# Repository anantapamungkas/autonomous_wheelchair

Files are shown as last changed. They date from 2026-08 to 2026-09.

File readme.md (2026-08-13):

## 📁 Struktur Repositori

Rrepositori terdiri dari beberapa komponen utama:
*   **`assets/`**: 
*   **`firmware/`**: 
*   **`hardware/`**: 
*   **`ros_ws/`**: 
*   **`scripts/`**: 

## Spesifikasi Perangkat Keras (Hardware)

<p align="center">
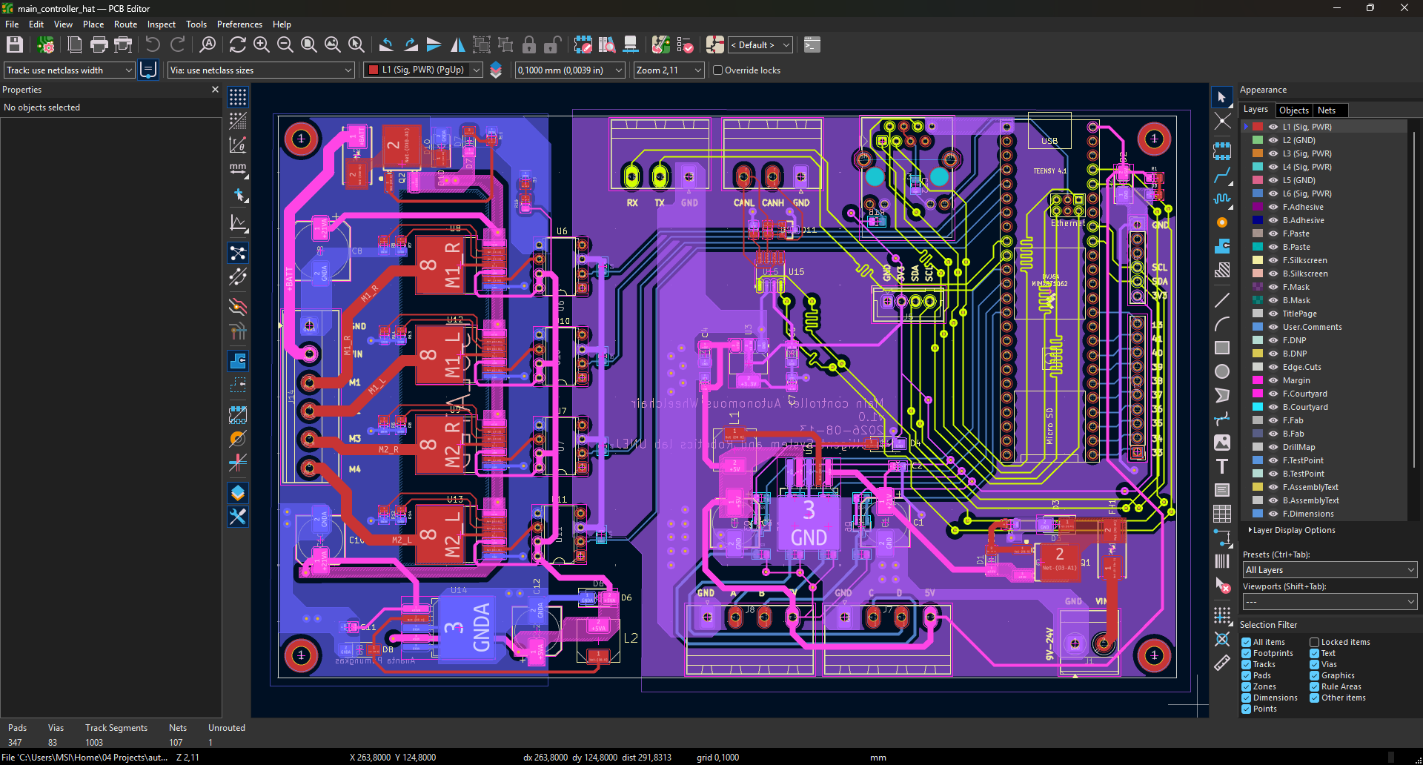
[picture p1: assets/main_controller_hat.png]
Sistem Arsitektur Kursi Roda Otonom
  
</p>

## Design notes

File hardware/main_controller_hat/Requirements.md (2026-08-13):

# Hardware Requirements & System Architecture Document

**Project Name:** Autonomous Wheelchair Main Controller
**Document Owner:** Ananta Pamungkas  
**Date:** 13-08-2026  
**Version:** 1.0

---

## 1. Executive Summary

## 2. System Objectives

## 3. Functional Requirements
### 3.1 Core Processing & Firmware

### 3.2 Power Management & Distribution

### 3.3 Sensing & Inputs (Peripherals)

### 3.4 Actuation & Outputs

## 4. Non-Functional Requirements

## 5. System Architecture
### 5.1 High-Level Block Diagram

### 5.2 Communication Buses & Bandwidth

## 6. Subsystem Validation & Prototyping Plan

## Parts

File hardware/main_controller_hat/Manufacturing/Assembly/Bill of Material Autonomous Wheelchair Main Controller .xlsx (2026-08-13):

Total
Rp 355483
Barang | Jenis | Jumlah | Satuan | Harga Satuan | Total Harga | Ongkir | Link Pembelian
cap elco(polar)_8x10_220uF | Capacitor | 4 | pcs | Rp 1000 | Rp 4000 |  | https://tk.tokopedia.com/ZS4wJxB6g/
cap tantalum_0805_1uF | Capacitor | 1 | strip | Rp 5000 | Rp 5000 |  | https://tk.tokopedia.com/ZS4wSyJWV/
cap tantalum_0805_4.7uF | Capacitor | 2 | pcs | Rp 1000 | Rp 2000 |  | https://tk.tokopedia.com/ZS4wRrhET/
cap elco(polar)_10x10_470uF | Capacitor | 1 | pcs | Rp 4000 | Rp 4000 |  | https://tk.tokopedia.com/ZS4wLvY1n/
cap tantalum_0805_100nF | Capacitor | 1 | strip | Rp 2500 | Rp 2500 |  | https://tk.tokopedia.com/ZS4wAxYDJ/
res smd_0805_2.2K | Resistor | 1 | strip | Rp 1500 | Rp 1500 |  | https://tk.tokopedia.com/ZS4wMq25k/
res smd_0805_100K | Resistor | 1 | strip | Rp 1000 | Rp 1000 |  | https://tk.tokopedia.com/ZS4oMhxKQ/
res smd_0805_10K | Resistor | 2 | strip | Rp 1000 | Rp 2000 |  | https://tk.tokopedia.com/ZS4wMEAE6/
res smd_0805_120 | Resistor | 1 | strip | Rp 1500 | Rp 1500 |  | https://tk.tokopedia.com/ZS4wpNDbM/
res smd_0805_1K | Resistor | 1 | strip | Rp 1000 | Rp 1000 |  | https://tk.tokopedia.com/ZS4wpRMPs/
diode_tvs(esd)_5V (LESD5Z5.0T1G) | Diode | 2 | pcs | Rp 899 | Rp 1798 |  | https://tk.tokopedia.com/ZS4wBeh6h/
diode_tvs(esd)_3V (LESD5Z3.3T1G) | Diode | 2 | pcs | Rp 899 | Rp 1798 |  | https://tk.tokopedia.com/ZS4wBrvKN/
diode_zener_10V (LL34) | Diode | 2 | pcs | Rp 845 | Rp 1690 |  | https://tk.tokopedia.com/ZS4wfYXWT/
diode_zener_11V (LL34) | Diode | 2 | pcs | Rp 845 | Rp 1690 |  | https://tk.tokopedia.com/ZS4wfS8Bo/
diode_schotty (SS34) | Diode | 2 | pcs | Rp 635 | Rp 1270 |  | https://tk.tokopedia.com/ZS4wUPosg/
diode_esd (PESD1CAN) | Diode | 1 | pcs | Rp 2546 | Rp 2546 |  | https://tk.tokopedia.com/ZS4wyAvPt/
diode_led_blue (LED 0805 SMD Biru ) | Diode | 2 | pcs | Rp 2000 | Rp 4000 |  | https://tk.tokopedia.com/ZS4wP6N2M/
fuse_holder | Fuse | 2 | pcs | Rp 3163 | Rp 6326 |  | https://tk.tokopedia.com/ZS4w59JFq/
fuse 3A | Fuse | 2 | pcs | Rp 2530 | Rp 5060 |  | https://tk.tokopedia.com/ZS4oMvqqV/
fuse 4A | Fuse | 2 | pcs | Rp 2530 | Rp 5060 |  | https://tk.tokopedia.com/ZS4orx7j3/
fuse 5A | Fuse | 2 | pcs | Rp 2530 | Rp 5060 |  | https://tk.tokopedia.com/ZS4wmRkgq/
LM2596S-5 | ICs | 2 | pcs | Rp 25000 | Rp 50000 |  | https://tk.tokopedia.com/ZS4waEnr3/
AMS1117-3.3 | ICs | 1 | pcs | Rp 2500 | Rp 2500 |  | https://tk.tokopedia.com/ZS4wa7tE5/
6N137 (optocoupler) | ICs | 4 | pcs | Rp 9000 | Rp 36000 |  | https://tk.tokopedia.com/ZS4wmX5g8/
SN65HVD230 | ICs | 1 | pcs | Rp 22828 | Rp 22828 |  | https://tk.tokopedia.com/ZS4wue4fP/
BTS7960 (Driver Motor) | ICs | 4 | pcs | Rp 21000 | Rp 84000 |  | https://tk.tokopedia.com/ZS4wuGqSw/
Inductor_33uH | Inductor | 2 | pcs | Rp 4000 | Rp 8000 |  | https://tk.tokopedia.com/ZS4wHDvvq/
IRFR5305 | Transistor | 2 | pcs | Rp 24900 | Rp 49800 |  | https://tk.tokopedia.com/ZS4w91Kqe/
BSS138 | Transistor | 4 | pcs | Rp 1000 | Rp 4000 |  | https://tk.tokopedia.com/ZS4w9BYNe/
KF2EDG-3p | Terminal / Connector | 2 | buah | Rp 4500 | Rp 9000 |  | https://tk.tokopedia.com/ZS4wCQL4b/
KF2EDG-4p | Terminal / Connector | 2 | buah | Rp 6000 | Rp 12000 |  | https://tk.tokopedia.com/ZS4wC4dEW/
RJ45 | Terminal / Connector | 1 | buah | Rp 5500 | Rp 5500 |  | https://tk.tokopedia.com/ZS4w4qQNN/
KF128-2p | Terminal / Connector | 1 | buah | Rp 1800 | Rp 1800 |  | https://tk.tokopedia.com/ZS4wgyw8m/
KF128-6p | Terminal / Connector | 1 | buah | Rp 2600 | Rp 2600 |  | https://tk.tokopedia.com/ZS4wgAeRV/
pin header | Terminal / Connector | 4 | buah | Rp 1000 | Rp 4000 |  | https://tk.tokopedia.com/ZS4wgnHRS/
JST XH 2.54 | Terminal / Connector | 1 | buah | Rp 2657 | Rp 2657 |  | https://tk.tokopedia.com/ZS4wp5hqA/

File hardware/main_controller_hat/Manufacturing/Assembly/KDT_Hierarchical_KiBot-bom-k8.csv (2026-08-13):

# | Qty | Reference | Value | Datasheet | Footprint | Description | Manufacturer | Manufacturer Part Number
1 | 83 | C1,C2,C3,C4,C5,C6,C7,C8,C10,C11,C12,C13,D1,D2,D3,D4,D5,D6,D7,D8,D9,D10,D11,FH1,FH2,J1,J2,J3,J4,J5,J6,J7,J8,J9,J14,L1,L2,Q1,Q2,Q3,Q4,Q5,Q6,R1,R2,R3,R4,R5,R6,R7,R8,R9,R10,R11,R12,R13,R14,R15,R16,R17,R18,R19,R20,R21,R22,R23,R24,R25,R26,R27,U1,U3,U5,U6,U7,U8,U9,U10,U11,U12,U13,U14,U15 | 01550900M,100K,100nF,10K,120,1K,1uF,2.2K,21V Li ion,220uF,33uH,4.7uF,470uF,6N137,AMS1117-3.3,BSS138,BTS7960B,BZV55B12,Blue,CAN 1,CMPS14,Conn_01x04_Pin,Conn_01x10_Pin,D_TVS,ENC A,ENC B,IRFR5305,LM2596S-5,PESD1CAN,215,RJ45_Hanrun_HR911105A_Horizontal,SMAJ24A,SN65HVD230,SS34,Screw_Terminal_01x06,Teensy4.1,UART | http://www.advanced-monolithic.com/pdf/ds1117.pdf,http://www.ti.com/lit/ds/symlink/lm2596.pdf,http://www.ti.com/lit/ds/symlink/sn65hvd230.pdf,https://assets.n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 | BTS7960B:DPAK127P1490X440-8N,Capacitor_SMD:CP_Elec_10x10,Capacitor_SMD:CP_Elec_8x10.5,Capacitor_SMD:C_0603_1608Metric,Capacitor_SMD:C_0603_1608Metric_Pad1.08x0.95mm_HandSolder,Capacitor_SMD:C_1206_3216Metric_Pad1.33x1.80mm_HandSolder,Connector_JST:JST_XH_B4B-XH-A_1x04_P2.50mm_Vertical,Connector_Phoenix_MSTB:PhoenixContact_MSTBA_2,5_3-G-5,08_1x03_P5.08mm_Horizontal,Connector_Phoenix_MSTB:PhoenixContact_MSTBA_2,5_4-G-5,08_1x04_P5.08mm_Horizontal,Connector_PinHeader_2.54mm:PinHeader_1x06_P2.54mm_Vertical,Connector_PinHeader_2.54mm:PinHeader_1x10_P2.54mm_Vertical,Connector_RJ:RJ45_Hanrun_HR911105A_Horizontal,DR74-330-R:INDM7676X435N,Diode_SMD:D_MiniMELF,Diode_SMD:D_SMA,PCM_SparkFun-LED:LED_0805_2012Metric,PCM_SparkFun-Resistor:R_0805_2012Metric,Package_DIP:DIP-8_W7.62mm,Package_SO:SOIC-8_3.9x4.9mm_P1.27mm,Package_TO_SOT_SMD:SOT-223-3_TabPin2,Package_TO_SOT_SMD:SOT-23,Package_TO_SOT_SMD:TO-263-5_TabPin3,Resistor_SMD:R_0603_1608Metric_Pad0.98x0.95mm_HandSolder,TerminalBlock_Phoenix:TerminalBlock_Phoenix_MKDS-1,5-6-5.08_1x06_P5.08mm_Horizontal,TerminalBlock_Phoenix:TerminalBlock_Phoenix_MKDS-3-2-5.08_1x02_P5.08mm_Horizontal,easyeda2kicad:FUSE-SMD_L9.8-W5.0_01550900M,easyeda2kicad:SMA_L4.4-W2.8-LS5.4-R-RD,easyeda2kicad:SOT-23_L2.9-W1.3-P1.90-LS2.4-BR,easyeda2kicad:TO-252-3_L6.6-W6.1-P4.58-LS10.1-BR-1,teensy:Teensy41 | 1 Port RJ45 Magjack Connector Through Hole 10/100 Base-T, AutoMDIX,12V, 500mW, 2%, Zener diode, MiniMELF,1A Low Dropout regulator, positive, 3.3V fixed output, SOT-223,400W unidirectional Transient Voltage Suppressor, 24.0Vr, SMA(DO-214AC),50V Vds, 0.22A Id, N-Channel MOSFET, SOT-23,5V 3A Step-Down Voltage Regulator, TO-263,Bidirectional transient-voltage-suppression diode,CAN Bus Transceivers, 3.3V, 1Mbps, Low-Power capabilities, SOIC-8,Generic connector, single row, 01x02, script generated,Generic connector, single row, 01x04, script generated,Generic connector, single row, 01x06, script generated,Generic connector, single row, 01x10, script generated,Generic screw terminal, single row, 01x03, script generated (kicad-library-utils/schlib/autogen/connector/),Generic screw terminal, single row, 01x04, script generated (kicad-library-utils/schlib/autogen/connector/),Generic screw terminal, single row, 01x06, script generated (kicad-library-utils/schlib/autogen/connector/),Inductor,Light emitting diode,PESD1CAN,Polarized capacitor,Polarized capacitor, US symbol,Resistor,Schottky diode,Single High Speed LSTTL/TTL Compatible Optocoupler with enable, dV/dt 1000/us, VCM 10, max 7V VCC, DIP-8,Unpolarized capacitor | Littelfuse(美国力特),Nexperia(安世),Slkor(萨科微)

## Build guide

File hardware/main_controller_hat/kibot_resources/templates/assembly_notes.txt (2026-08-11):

ASSEMBLY NOTES (UNLESS OTHERWISE SPECIFIED)

1)	DO NOT POPULATE PARTS ARE MARKED WITH A RED CROSS.

2)	DO NOT POPULATE PARTS ARE NOT PRESENT IN THE BOM.

3)	IF CONFLICTING INFORMATION IS FOUND BETWEEN THE ASSEMBLY
	FILE AND BOM, BOM SHOULD BE USED AS THE MAIN SOURCE.

4)	CONFORMAL COATING IS NOT REQUIRED.

5)	DOT IDENTIFIES PIN #1 LOCATION AND DEVICE ORIENTATION
	WHEN VIEWED FROM THE TOP.

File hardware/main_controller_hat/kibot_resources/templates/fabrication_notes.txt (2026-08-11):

FABRICATION NOTES (UNLESS OTHERWISE SPECIFIED)

1)	FABRICATE PER IPC-6012A CLASS 2.

2)	OUTLINE DEFINED IN SEPARATE GERBER FILE WITH
	"Edge_Cuts.GBR" SUFFIX.

	DIMENSIONS OF CIRCUMSIZED RECTANGLE SHOWN ON THIS
	DRAWING FOR REFERENCE ONLY.

3)	SEE SEPARATE DRILL FILES WITH ".DRL" SUFFIX 
	FOR HOLE LOCATIONS.

	SELECTED HOLE LOCATIONS SHOWN ON THIS DRAWING 
	FOR REFERENCE ONLY.

4)	SURFACE FINISH: ${pcb_finish_cap}

5)	SOLDERMASK ON BOTH SIDES OF THE BOARD SHALL 
	BE LPI, COLOR ${solder_mask_color_text_cap}.

6)	SILK SCREEN LEGEND TO BE APPLIED PER LAYER 
	STACKUP USING ${silk_screen_color_text_cap} NON-CONDUCTIVE EPOXY INK.

7)	ALL VIAS ARE TENTED ON BOTH SIDES UNLESS 
	SOLDERMASK OPENED IN GERBER.

8)	VENDOR SHOULD FOLLOW ROHS COMPLIANT PROCESS 
	AND Pb FREE FOR MANUFACTURING

9)	PCB MATERIAL REQUIREMENTS:

	A.	FLAMMABILITY RATING MUST MEET OR EXCEED 
		UL94V-0 REQUIREMENTS.
	B.	Tg 170 C OR EQUIVALENT.
	C.	EQUIVALENT MATERIAL SHALL BE RoHS COMPLIANT, 
		HALOGEN FREE AND APPROVED BY ${COMPANY_cap}.

10)	DESIGN GEOMETRY MINIMUM FEATURE SIZES:

	BOARD SIZE				${bb_w_mm} × ${bb_h_mm} mm
	BOARD THICKNESS		${thickness_mm} mm
	TRACE WIDTH			${track_mm} mm
	TRACE TO TRACE		${clearance_mm} mm
	MIN. HOLE (PTH)			${drill_pth_real_mm} mm
	MIN. HOLE (NPTH)		${drill_npth_real_mm} mm
	ANNULAR RING			${oar_mm} mm
	COPPER TO HOLE		${c2h_mm} mm
	COPPER TO EDGE		${c2e_mm} mm
	HOLE TO HOLE			${h2h_mm} mm
#?stackup and impedance_controlled

#?stackup and impedance_controlled
11)	REFER TO IMPEDANCE TABLE FOR IMPEDANCE CONTROL REQUIREMENTS.
#?stackup and impedance_controlled

#?stackup and impedance_controlled
12)	CONFIRM SPACE WIDTHS AND SPACINGS.

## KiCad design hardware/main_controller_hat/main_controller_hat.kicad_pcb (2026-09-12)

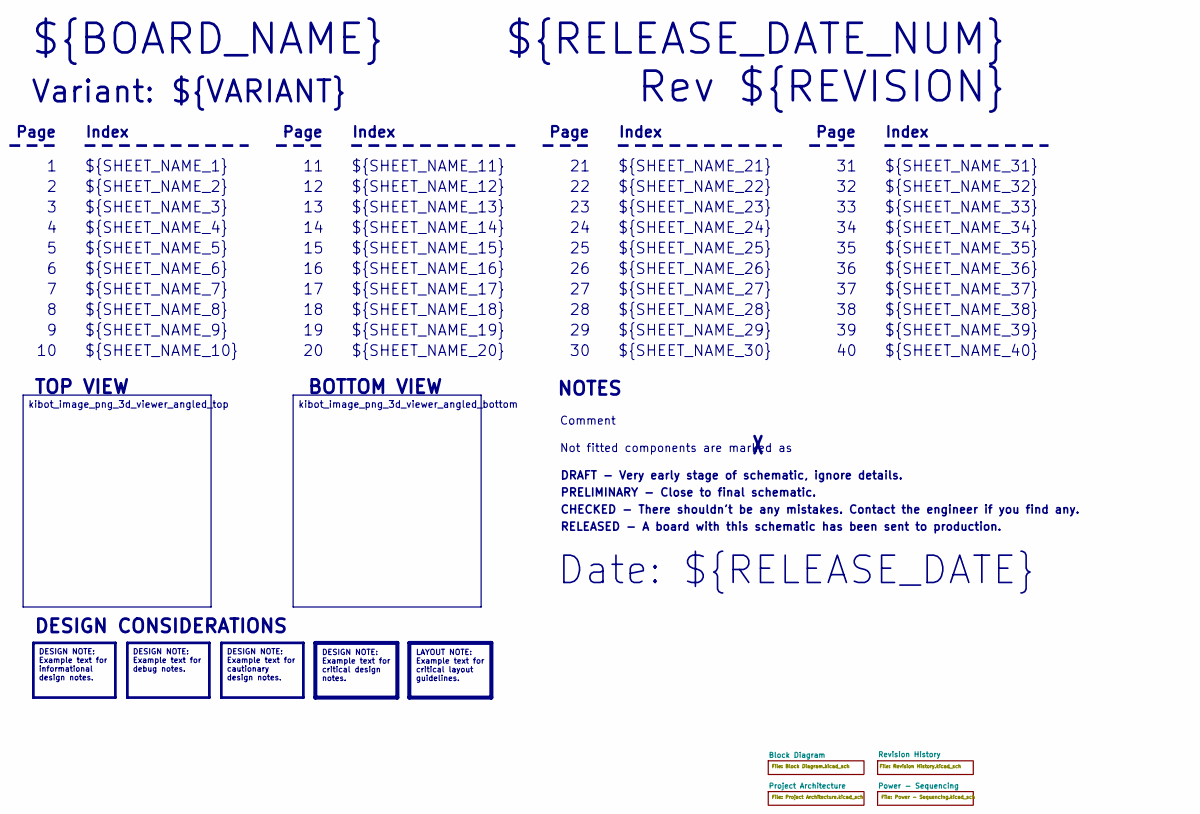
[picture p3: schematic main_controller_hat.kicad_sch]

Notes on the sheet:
Variant: ${VARIANT}
RELEASED - A board with this schematic has been sent to production.
${SHEET_NAME_24}
Index
Page
PRELIMINARY - Close to final schematic.
${SHEET_NAME_22}
DRAFT - Very early stage of schematic, ignore details.
${SHEET_NAME_12}
${SHEET_NAME_8}
${SHEET_NAME_2}
${SHEET_NAME_5}
${SHEET_NAME_20}
${SHEET_NAME_23}
${RELEASE_DATE_NUM}
${SHEET_NAME_35}
Not fitted components are marked as
${SHEET_NAME_11}
${SHEET_NAME_6}
${SHEET_NAME_37}
${SHEET_NAME_26}
${SHEET_NAME_36}
Rev ${REVISION}
${SHEET_NAME_15}
CHECKED - There shouldn't be any mistakes. Contact the engineer if you find any.
BOTTOM VIEW
${SHEET_NAME_14}
${SHEET_NAME_21}
${SHEET_NAME_17}
${SHEET_NAME_18}
Date: ${RELEASE_DATE}
${SHEET_NAME_7}
${SHEET_NAME_31}
${BOARD_NAME}
NOTES
${SHEET_NAME_40}
${SHEET_NAME_39}
${SHEET_NAME_32}
${SHEET_NAME_1}
${SHEET_NAME_9}

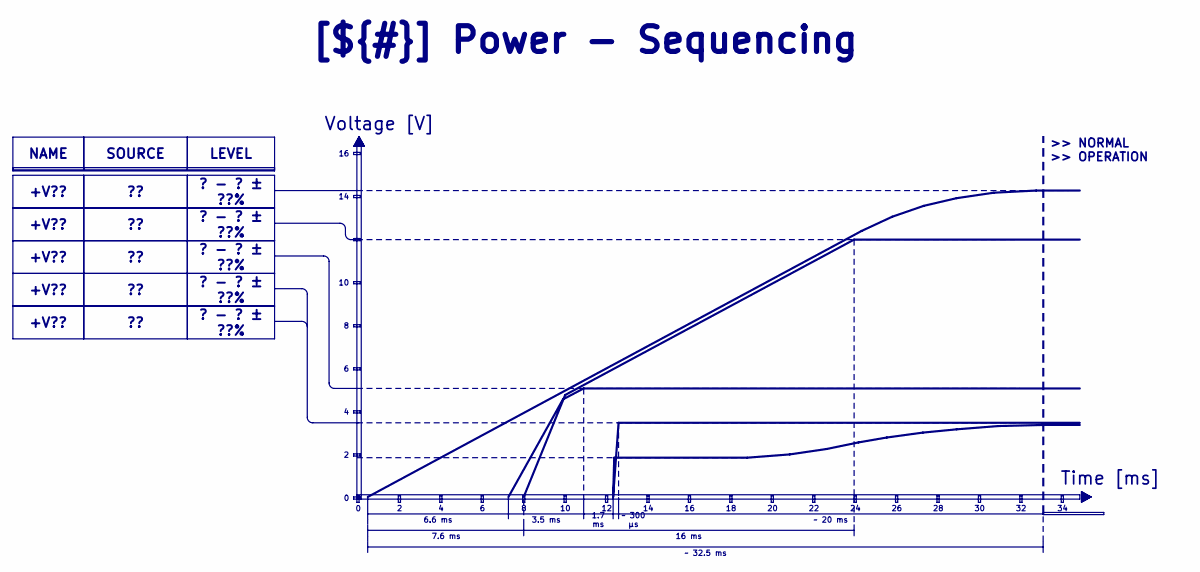
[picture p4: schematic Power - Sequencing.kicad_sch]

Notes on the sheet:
Voltage [V]
>> NORMAL >> OPERATION
Time [ms]
3.5 ms
7.6 ms
? - ? ± ??%
~ 300 μs
1.7 ms
16 ms
+V??
LEVEL
NAME
~ 20 ms
SOURCE
[${#}] ${TITLE}
6.6 ms
~ 32.5 ms

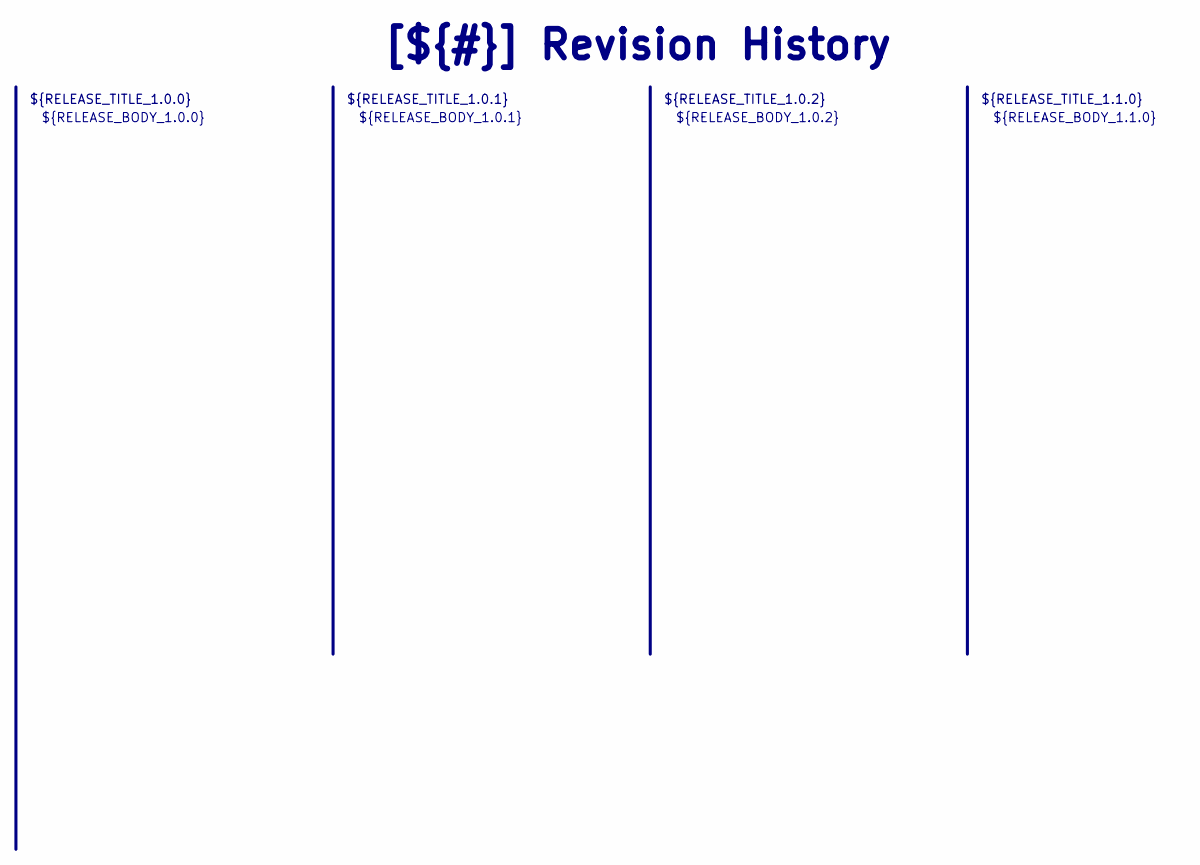
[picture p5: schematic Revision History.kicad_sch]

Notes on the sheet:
${RELEASE_BODY_1.1.0}
[${#}] ${TITLE}
${RELEASE_BODY_1.0.0}
${RELEASE_TITLE_1.0.2}
${RELEASE_BODY_1.0.2}
${RELEASE_BODY_1.0.1}
${RELEASE_TITLE_1.0.0}
${RELEASE_TITLE_1.0.1}
${RELEASE_TITLE_1.1.0}

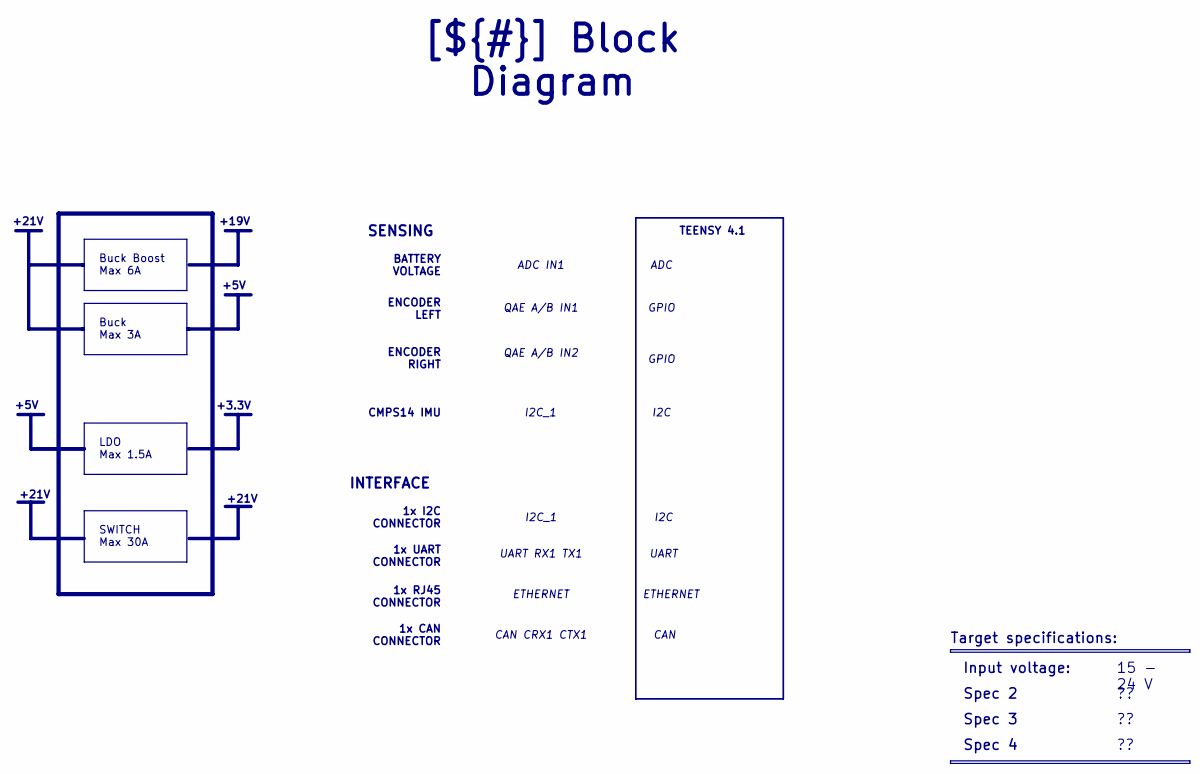
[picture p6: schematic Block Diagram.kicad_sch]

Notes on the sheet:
+21V
+5V
TEENSY 4.1
+3.3V
+19V
CMPS14 IMU
Spec 4
15 - 24 V
ENCODER LEFT ENCODER RIGHT
1x CAN CONNECTOR
ETHERNET
ADC
Buck Boost Max 6A
1x UART CONNECTOR
LDO Max 1.5A
CAN CRX1 CTX1
QAE A/B IN1
UART
GPIO
I2C
[${#}] ${TITLE}
QAE A/B IN2
Input voltage:
SENSING
1x RJ45 CONNECTOR
Target specifications:
1x I2C CONNECTOR
Spec 3
Spec 2
I2C_1
Buck Max 3A
BATTERY VOLTAGE
ADC IN1
SWITCH Max 30A
UART RX1 TX1
CAN
INTERFACE

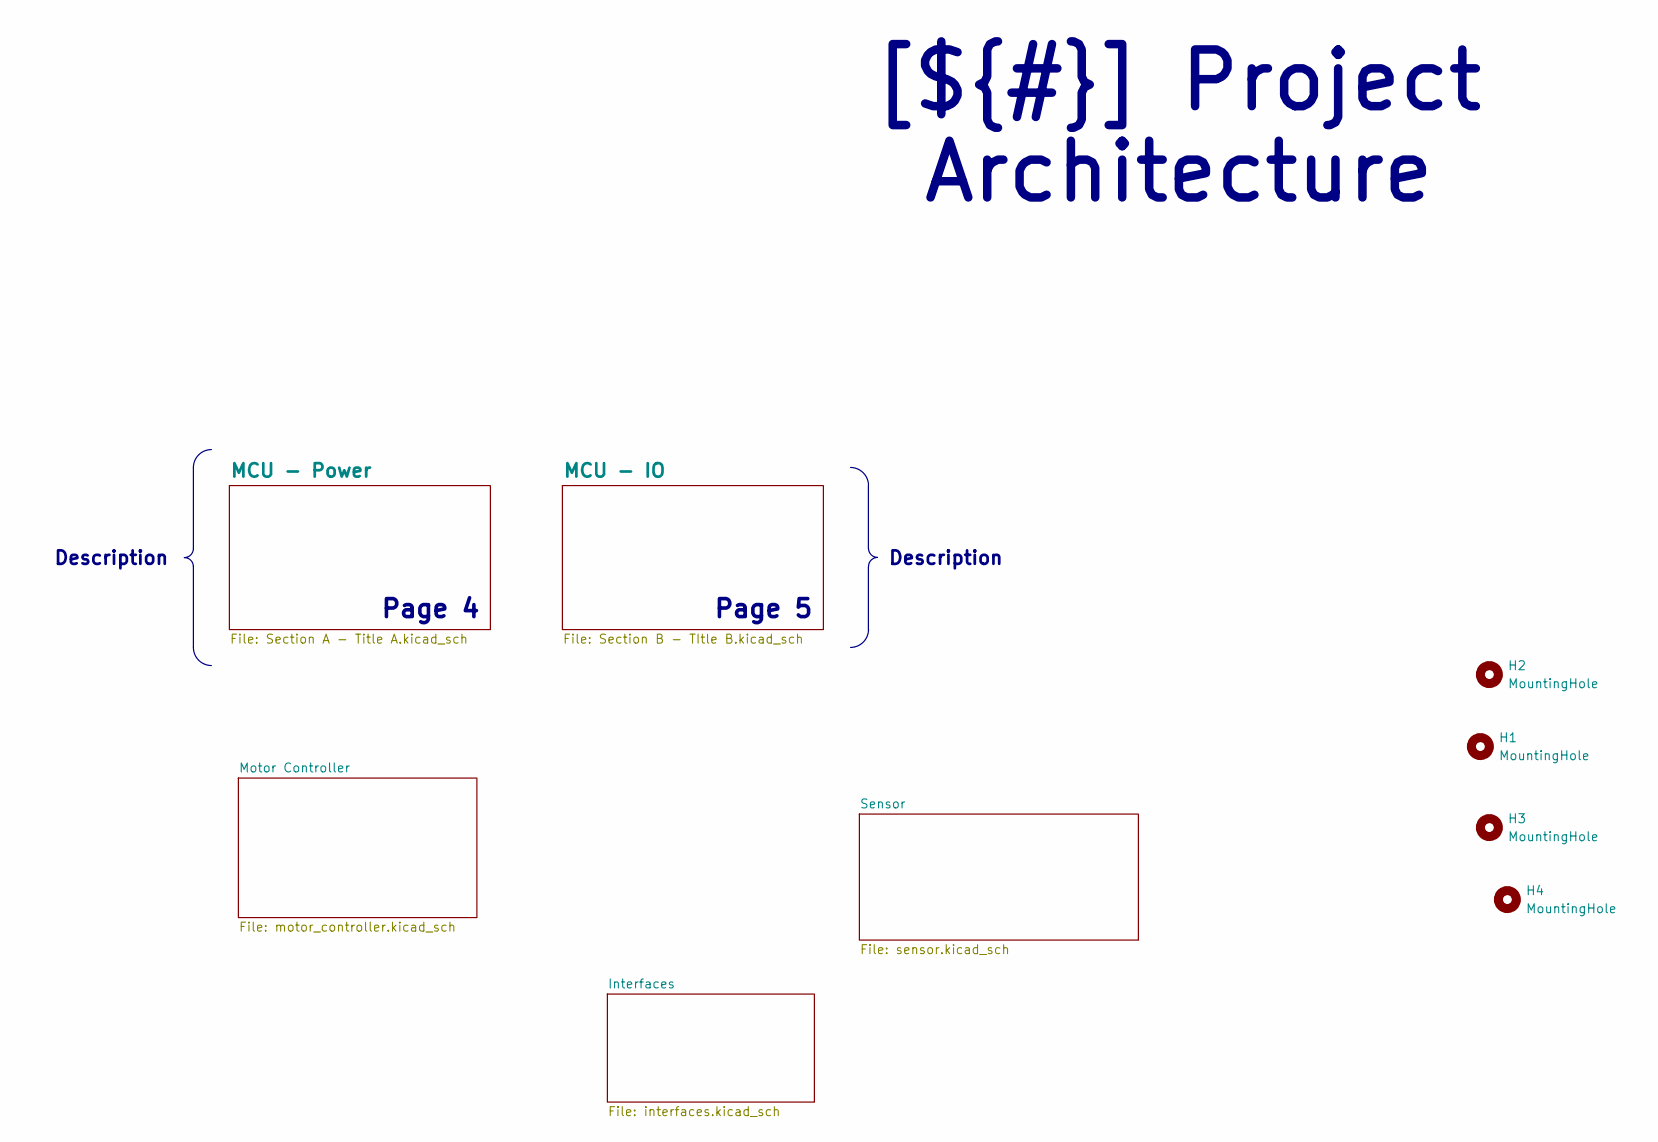
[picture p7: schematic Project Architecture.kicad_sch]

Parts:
H1, H2, H3, H4: MountingHole; MountingHole_3.2mm_M3_DIN965_Pad_TopBottom

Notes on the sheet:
Page 5
Page 4
Description
[${#}] ${TITLE}

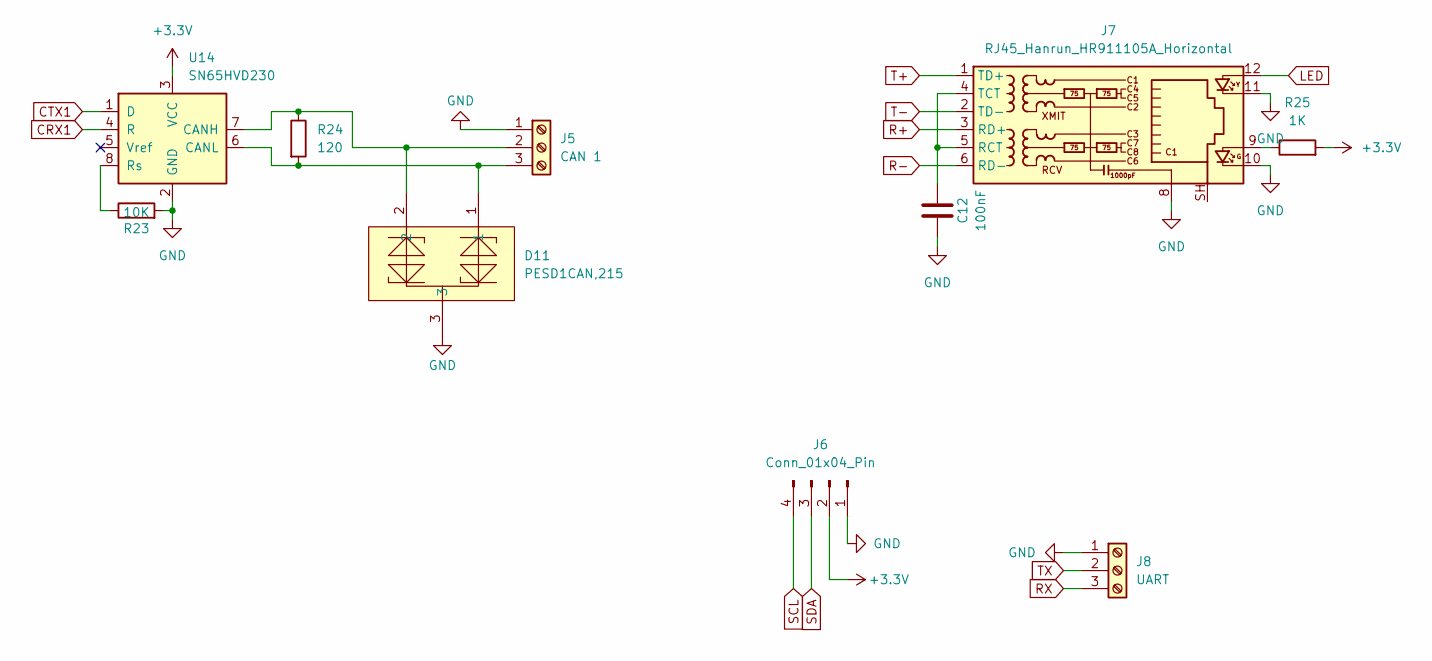
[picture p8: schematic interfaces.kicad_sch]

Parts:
C12: 100nF; C_0805_2012Metric
D11: PESD1CAN,215; SOT-23_L2.9-W1.3-P1.90-LS2.4-BR; MPN PESD1CAN,215; LCSC Part C15771
J5: CAN 1; PhoenixContact_MSTBA_2,5_3-G-5,08_1x03_P5.08mm_Horizontal
J6: Conn_01x04_Pin; JST_XH_B4B-XH-A_1x04_P2.50mm_Vertical
J7: RJ45_Hanrun_HR911105A_Horizontal
J8: UART; PhoenixContact_MSTBA_2,5_3-G-5,08_1x03_P5.08mm_Horizontal
R23: 10K; R_0805_2012Metric
R24: 120; R_0805_2012Metric
R25: 1K; R_0805_2012Metric
U14: SN65HVD230; SOIC-8_3.9x4.9mm_P1.27mm

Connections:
+3.3V: J6.2, R25.2, U14.3 (VCC); also elsewhere on the board
CRX1: U14.4 (R); also elsewhere on the board
CTX1: U14.1 (D); also elsewhere on the board
GND: C12.1, D11.3, J5.1, J6.1, J7.8, J7.10, J7.11, J8.1, R23.2, U14.2 (GND); also elsewhere on the board
LED: J7.12; also elsewhere on the board
unnamed: D11.2, J5.2, R24.1, U14.7 (CANH)
unnamed: D11.1, J5.3, R24.2, U14.6 (CANL)
unnamed: J7.9, R25.1
unnamed: C12.2, J7.4 (TCT), J7.5 (RCT)
unnamed: R23.1, U14.8 (Rs)
R+: J7.3 (RD+); also elsewhere on the board
R-: J7.6 (RD-); also elsewhere on the board
RX: J8.3; also elsewhere on the board
SCL: J6.4; also elsewhere on the board
SDA: J6.3; also elsewhere on the board
T+: J7.1 (TD+); also elsewhere on the board
T-: J7.2 (TD-); also elsewhere on the board
TX: J8.2; also elsewhere on the board

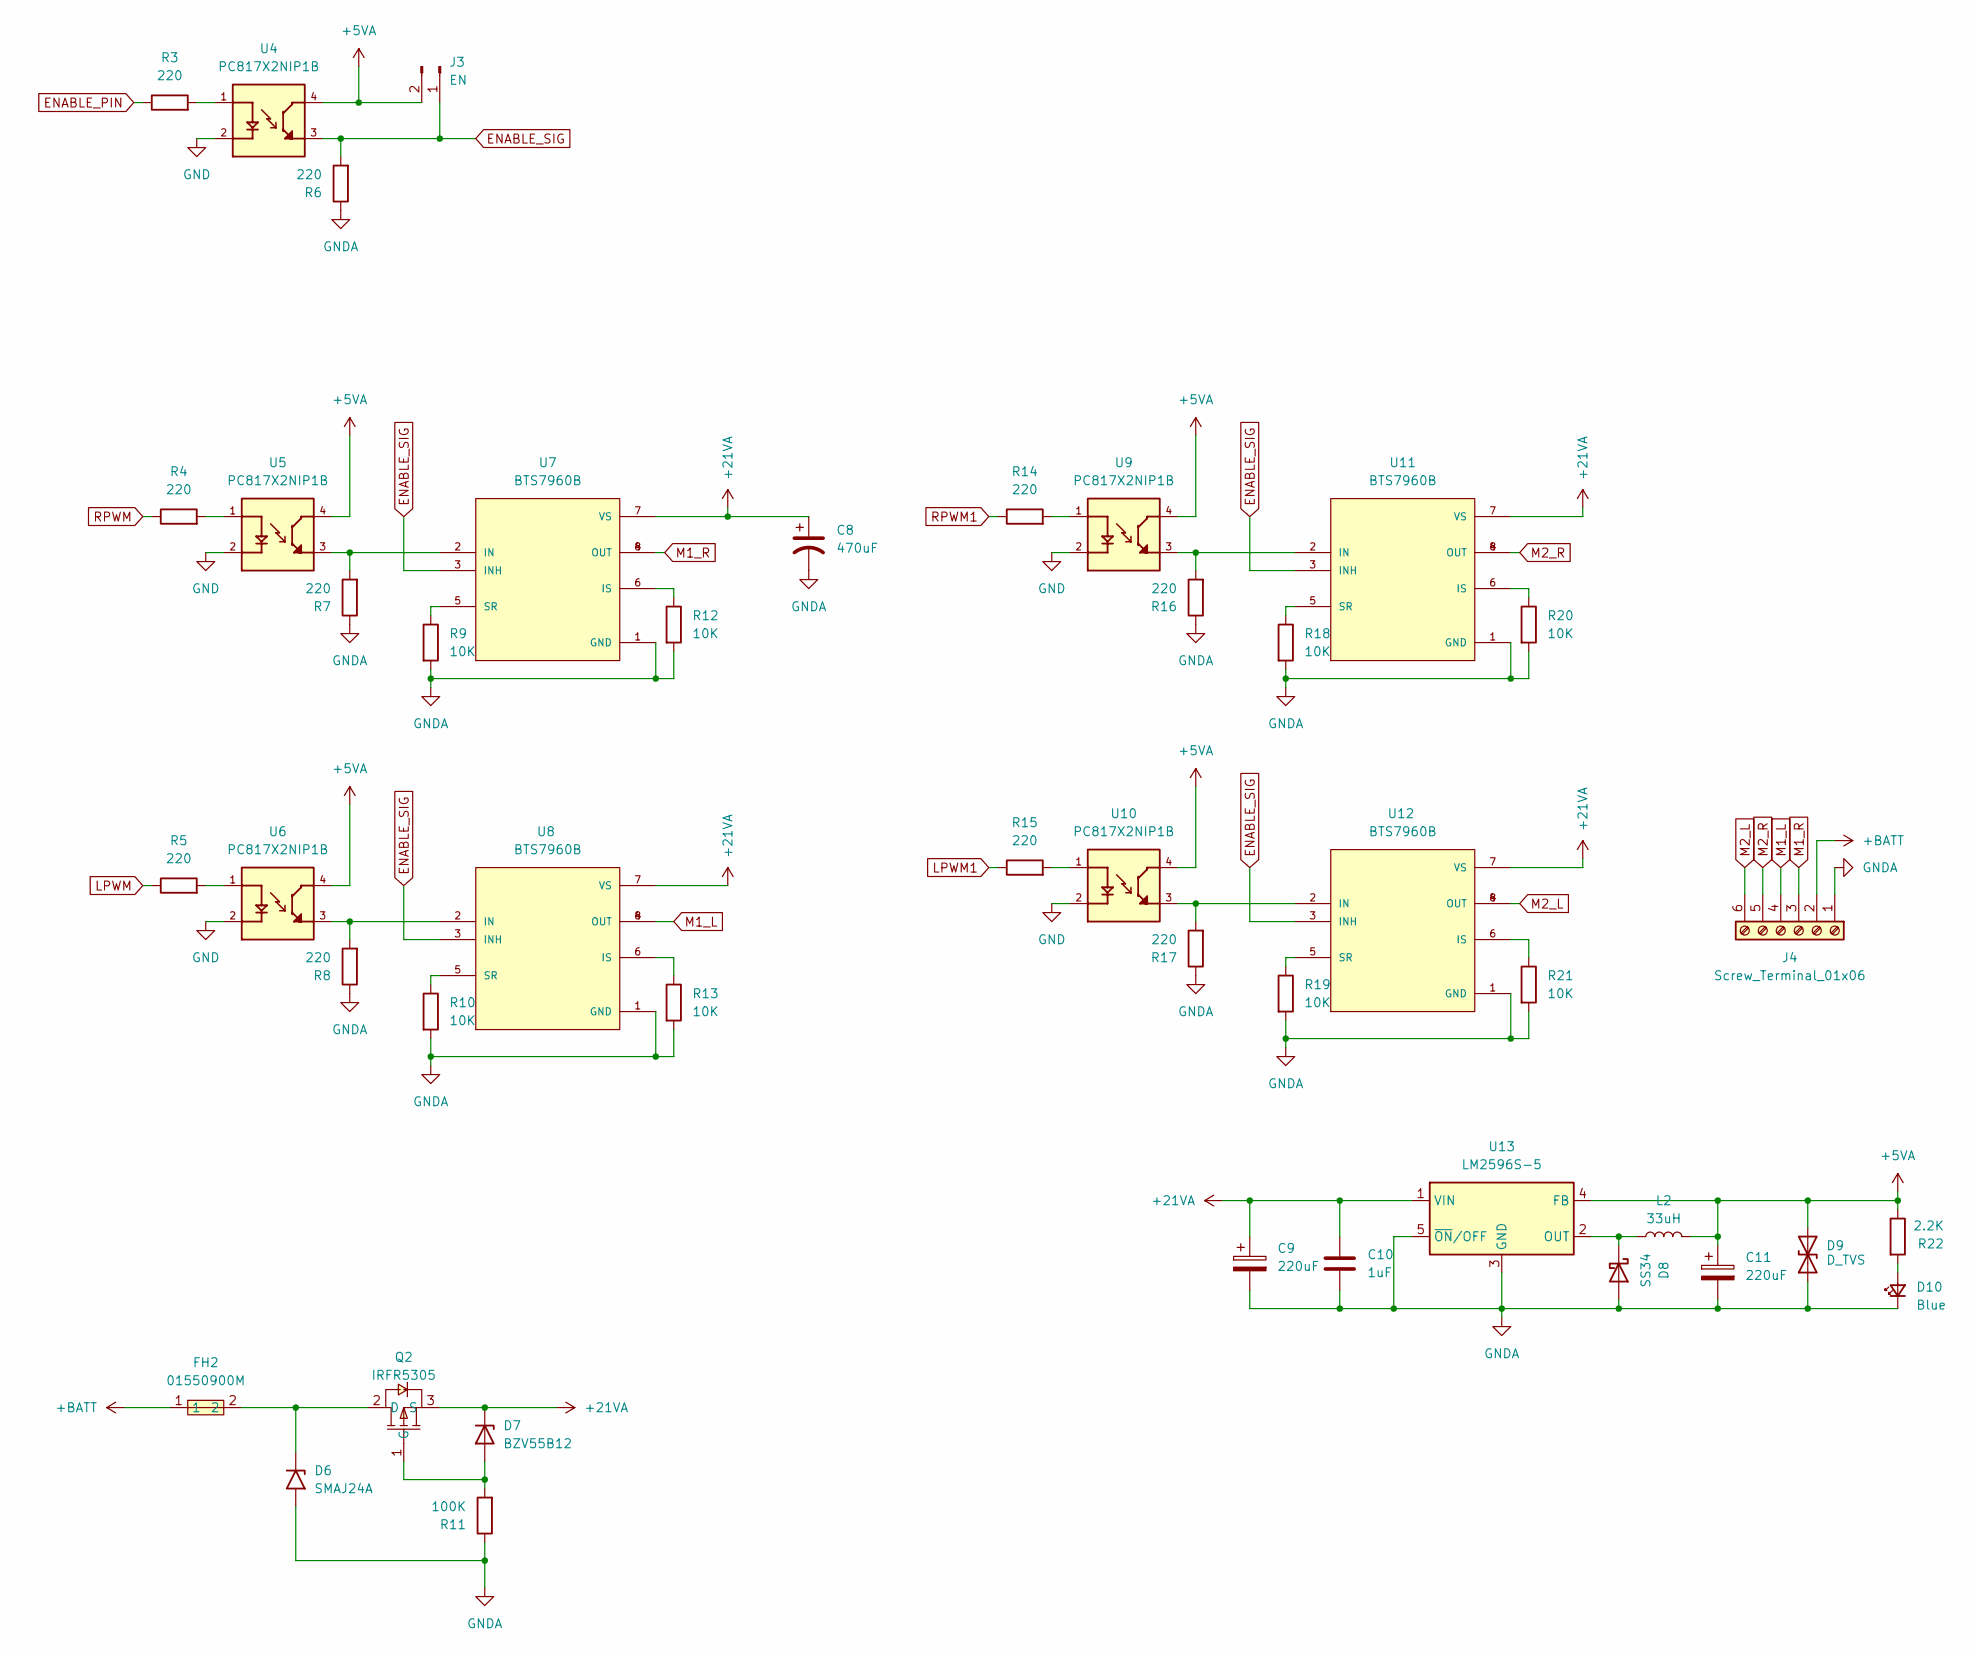
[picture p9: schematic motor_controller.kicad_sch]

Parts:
C8: 470uF; CP_Elec_10x10; Voltage 50V
C9, C11: 220uF; CP_Elec_8x10.5
C10: 1uF; C_0805_2012Metric
D6: SMAJ24A; D_SMA
D7: BZV55B12; D_MiniMELF
D8: SS34; SMA_L4.4-W2.8-LS5.4-R-RD
D9: D_TVS; D_SMA
D10: Blue; LED_0805_2012Metric
FH2: 01550900M; FUSE-SMD_L9.8-W5.0_01550900M; MPN 01550900M; LCSC Part C108518
J3: EN; PinSocket_1x02_P2.54mm_Vertical
J4: Screw_Terminal_01x06; TerminalBlock_Phoenix_MKDS-1,5-6-5.08_1x06_P5.08mm_Horizont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
L2: 33uH; INDM7676X435N
Q2: IRFR5305; TO-252-3_L6.6-W6.1-P4.58-LS10.1-BR-1; MPN IRFR5305; LCSC Part C5155388
R3, R4, R5, R6, R7, R8, R14, R15, R16, R17: 220; R_0805_2012Metric
R9, R10, R12, R13, R18, R19, R20, R21: 10K; R_0805_2012Metric
R11: 100K; R_0805_2012Metric
R22: 2.2K; R_0805_2012Metric
U4, U5, U6, U9, U10: PC817X2NIP1B; SOIC254P960X420-4N; PARTREV October 12, 2016
U7, U8, U11, U12: BTS7960B; DPAK127P1490X440-8N; PARTREV 1.1
U13: LM2596S-5; TO-263-5_TabPin3

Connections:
+5VA: C11.1, D9.2 (A2), J3.2, L2.2, R22.1, U4.4, U5.4, U6.4, U9.4, U10.4, U13.4 (FB)
+21VA: C8.1, C9.1, C10.1, D7.1 (K), Q2.3 (S), U7.7 (VS), U8.7 (VS), U11.7 (VS), U12.7 (VS), U13.1 (VIN)
+BATT: FH2.1, J4.2
ENABLE_PIN: R3.1; also elsewhere on the board
ENABLE_SIG: J3.1, R6.2, U4.3, U7.3 (INH), U8.3 (INH), U11.3 (INH), U12.3 (INH)
GND: U4.2, U5.2, U6.2, U9.2, U10.2; also elsewhere on the board
GNDA: C8.2, C9.2, C10.2, C11.2, D6.2 (A2), D8.2 (A), D9.1 (A1), D10.1 (K), J4.1, R6.1, R7.1, R8.1, R9.2, R10.2, R11.1, R12.2, R13.2, R16.1, R17.1, R18.2, R19.2, R20.2, R21.2, U7.1 (GND), U8.1 (GND), U11.1 (GND), U12.1 (GND), U13.3 (GND), U13.5 (~ON/OFF)
LPWM: R5.1; also elsewhere on the board
LPWM1: R15.1; also elsewhere on the board
M1_L: J4.4, U8.4 (OUT), U8.8 (OUT)
M1_R: J4.3, U7.4 (OUT), U7.8 (OUT)
M2_L: J4.6, U12.4 (OUT), U12.8 (OUT)
M2_R: J4.5, U11.4 (OUT), U11.8 (OUT)
unnamed: D6.1 (A1), FH2.2, Q2.2 (D)
unnamed: D7.2 (A), Q2.1 (G), R11.2
unnamed: D8.1 (K), L2.1, U13.2 (OUT)
unnamed: D10.2 (A), R22.2
unnamed: R3.2, U4.1
unnamed: R4.2, U5.1
unnamed: R5.2, U6.1
unnamed: R14.2, U9.1
unnamed: R15.2, U10.1
unnamed: R7.2, U5.3, U7.2 (IN)
unnamed: R12.1, U7.6 (IS)
unnamed: R9.1, U7.5 (SR)
unnamed: R8.2, U6.3, U8.2 (IN)
unnamed: R13.1, U8.6 (IS)
unnamed: R10.1, U8.5 (SR)
unnamed: R16.2, U9.3, U11.2 (IN)
unnamed: R20.1, U11.6 (IS)
unnamed: R18.1, U11.5 (SR)
unnamed: R17.2, U10.3, U12.2 (IN)
unnamed: R21.1, U12.6 (IS)
unnamed: R19.1, U12.5 (SR)
RPWM: R4.1; also elsewhere on the board
RPWM1: R14.1; also elsewhere on the board

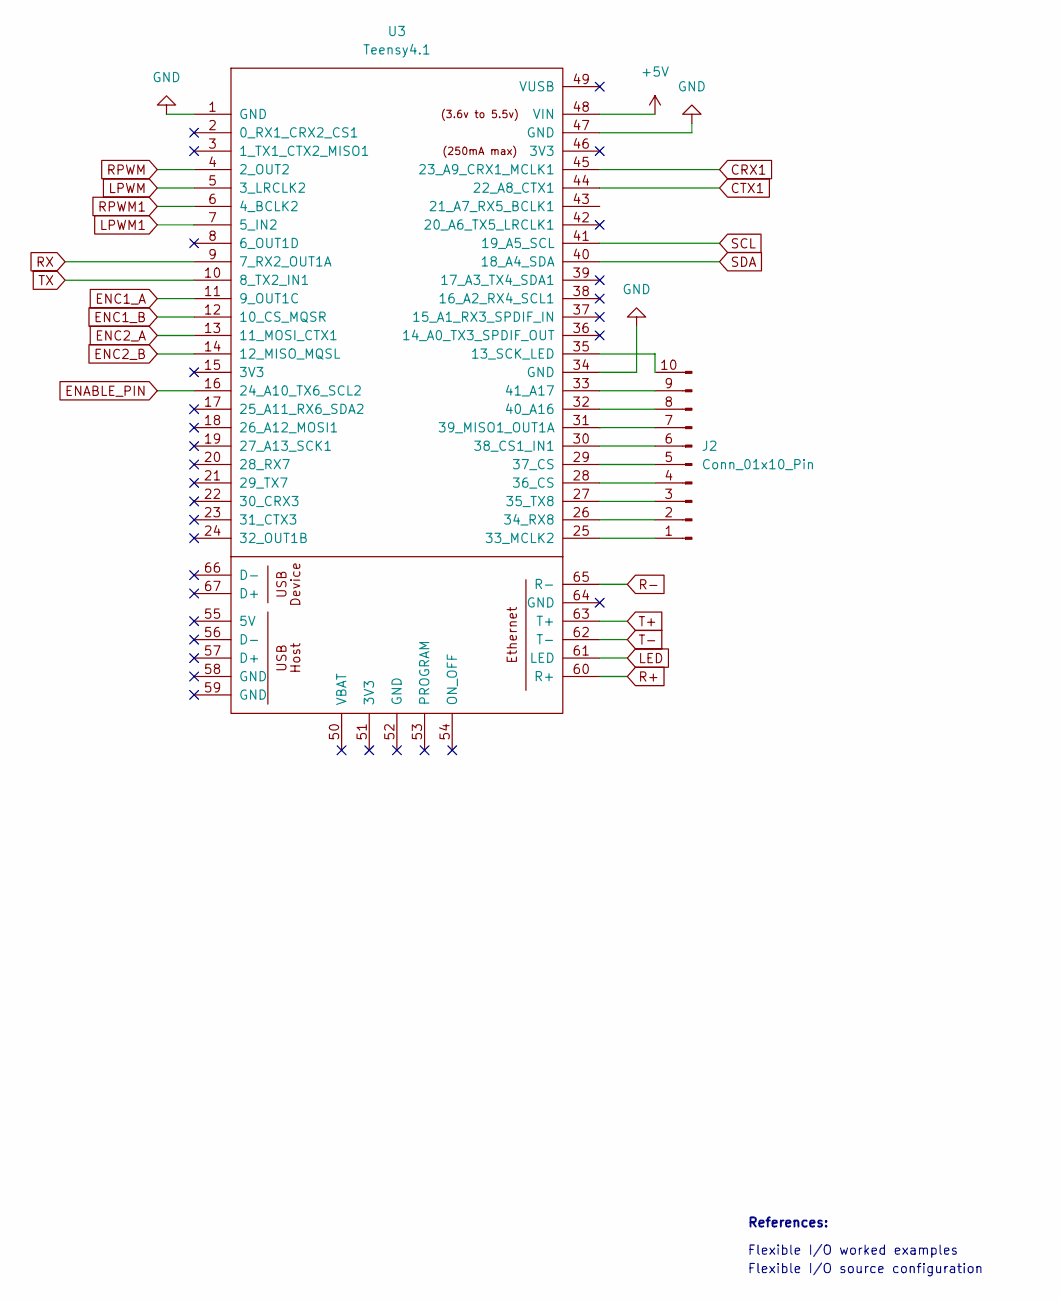
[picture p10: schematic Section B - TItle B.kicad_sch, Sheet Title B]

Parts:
J2: Conn_01x10_Pin; PinHeader_1x10_P2.54mm_Vertical
U3: Teensy4.1; Teensy41

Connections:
+5V: U3.48 (VIN); also elsewhere on the board
CRX1: U3.45 (23_A9_CRX1_MCLK1); also elsewhere on the board
CTX1: U3.44 (22_A8_CTX1); also elsewhere on the board
ENABLE_PIN: U3.16 (24_A10_TX6_SCL2); also elsewhere on the board
ENC1_A: U3.11 (9_OUT1C); also elsewhere on the board
ENC1_B: U3.12 (10_CS_MQSR); also elsewhere on the board
ENC2_A: U3.13 (11_MOSI_CTX1); also elsewhere on the board
ENC2_B: U3.14 (12_MISO_MQSL); also elsewhere on the board
GND: U3.1 (GND), U3.34 (GND), U3.47 (GND); also elsewhere on the board
LED: U3.61 (LED); also elsewhere on the board
LPWM: U3.5 (3_LRCLK2); also elsewhere on the board
LPWM1: U3.7 (5_IN2); also elsewhere on the board
unnamed: J2.1, U3.25 (33_MCLK2)
unnamed: J2.2, U3.26 (34_RX8)
unnamed: J2.3, U3.27 (35_TX8)
unnamed: J2.4, U3.28 (36_CS)
unnamed: J2.5, U3.29 (37_CS)
unnamed: J2.6, U3.30 (38_CS1_IN1)
unnamed: J2.7, U3.31 (39_MISO1_OUT1A)
unnamed: J2.8, U3.32 (40_A16)
unnamed: J2.9, U3.33 (41_A17)
unnamed: J2.10, U3.35 (13_SCK_LED)
R+: U3.60 (R+); also elsewhere on the board
R-: U3.65 (R-); also elsewhere on the board
RPWM: U3.4 (2_OUT2); also elsewhere on the board
RPWM1: U3.6 (4_BCLK2); also elsewhere on the board
RX: U3.9 (7_RX2_OUT1A); also elsewhere on the board
SCL: U3.41 (19_A5_SCL); also elsewhere on the board
SDA: U3.40 (18_A4_SDA); also elsewhere on the board
T+: U3.63 (T+); also elsewhere on the board
T-: U3.62 (T-); also elsewhere on the board
TX: U3.10 (8_TX2_IN1); also elsewhere on the board

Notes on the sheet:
Flexible I/O worked examples
References:
Flexible I/O source configuration

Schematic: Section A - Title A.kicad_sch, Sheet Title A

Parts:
C1, C3: 4.7uF; C_1206_3216Metric
C2, C4, C6: 1uF; C_0805_2012Metric
C5, C7: 220uF; CP_Elec_8x10.5
D1: SMAJ24A; D_SMA
D2: BZV55B12; D_MiniMELF
D3: SS34; SMA_L4.4-W2.8-LS5.4-R-RD
D4: D_TVS; D_SMA
D5: Blue; LED_0805_2012Metric
FH1: 01550900M; FUSE-SMD_L9.8-W5.0_01550900M; MPN 01550900M; LCSC Part C108518
J1: 21V Li ion; TerminalBlock_Phoenix_MKDS-3-2-5.08_1x02_P5.08mm_Horizontal
L1: 33uH; INDM7676X435N
Q1: IRFR5305; TO-252-3_L6.6-W6.1-P4.58-LS10.1-BR-1; MPN IRFR5305; LCSC Part C5155388
R1: 100K; R_0805_2012Metric
R2: 2.2K; R_0805_2012Metric
U1: AMS1117-3.3; SOT-223-3_TabPin2
U2: LM2596S-5; TO-263-5_TabPin3

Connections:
+3.3V: C3.1, C4.1, U1.2 (VO); also elsewhere on the board
+5V: C1.1, C2.1, C7.1, D4.2 (A2), L1.2, R2.1, U1.3 (VI), U2.4 (FB); also elsewhere on the board
+21V: C5.1, C6.1, D2.1 (K), Q1.3 (S), U2.1 (VIN)
GND: C1.2, C2.2, C3.2, C4.2, C5.2, C6.2, C7.2, D1.2 (A2), D3.2 (A), D4.1 (A1), D5.1 (K), J1.1, R1.1, U1.1 (GND), U2.3 (GND), U2.5 (~ON/OFF); also elsewhere on the board
unnamed: D1.1 (A1), FH1.2, Q1.2 (D)
unnamed: D2.2 (A), Q1.1 (G), R1.2
unnamed: D3.1 (K), L1.1, U2.2 (OUT)
unnamed: D5.2 (A), R2.2
unnamed: FH1.1, J1.2

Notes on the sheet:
J. Pieper ADC investigation
STM32G474 Datasheet p.81
AN5346

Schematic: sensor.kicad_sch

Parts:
J9: CMPS14; PinHeader_1x06_P2.54mm_Vertical
J10: ENC A; PhoenixContact_MSTBA_2,5_4-G-5,08_1x04_P5.08mm_Horizontal
J11: ENC B; PhoenixContact_MSTBA_2,5_4-G-5,08_1x04_P5.08mm_Horizontal
Q3, Q4, Q5, Q6: BSS138; SOT-23
R26, R27, R28, R29, R30, R31, R32, R33: 10K; R_0805_2012Metric

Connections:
+3.3V: J9.6, Q3.1 (G), Q4.1 (G), Q5.1 (G), Q6.1 (G), R26.1, R27.1, R30.1, R31.1; also elsewhere on the board
+5V: J10.4, J11.4, R28.1, R29.1, R32.1, R33.1; also elsewhere on the board
ENC1_A: Q3.2 (S), R26.2; also elsewhere on the board
ENC1_B: Q4.2 (S), R27.2; also elsewhere on the board
ENC2_A: Q5.2 (S), R30.2; also elsewhere on the board
ENC2_B: Q6.2 (S), R31.2; also elsewhere on the board
GND: J9.1, J10.1, J11.1; also elsewhere on the board
unnamed: J10.2, Q3.3 (D), R28.2
unnamed: J10.3, Q4.3 (D), R29.2
unnamed: J11.2, Q5.3 (D), R32.2
unnamed: J11.3, Q6.3 (D), R33.2
SCL: J9.4; also elsewhere on the board
SDA: J9.5; also elsewhere on the board

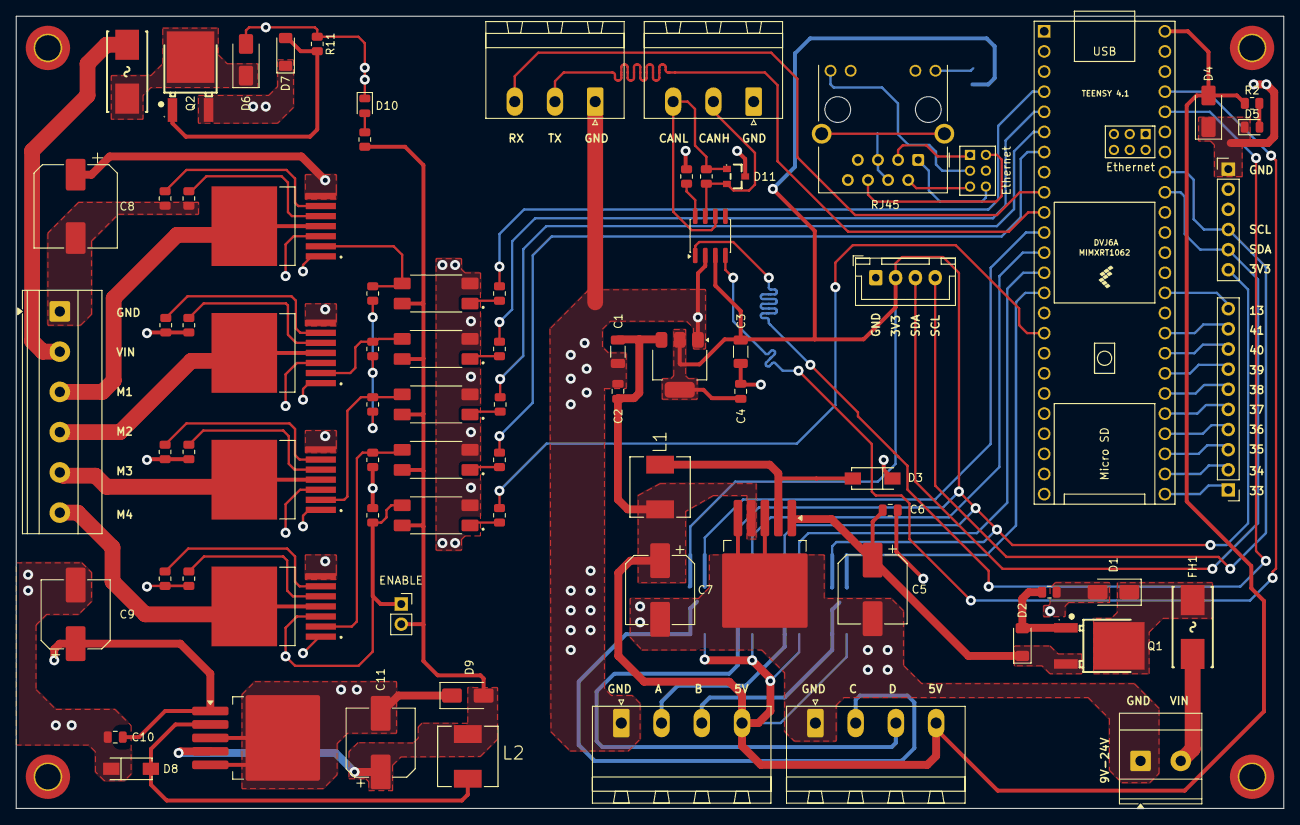
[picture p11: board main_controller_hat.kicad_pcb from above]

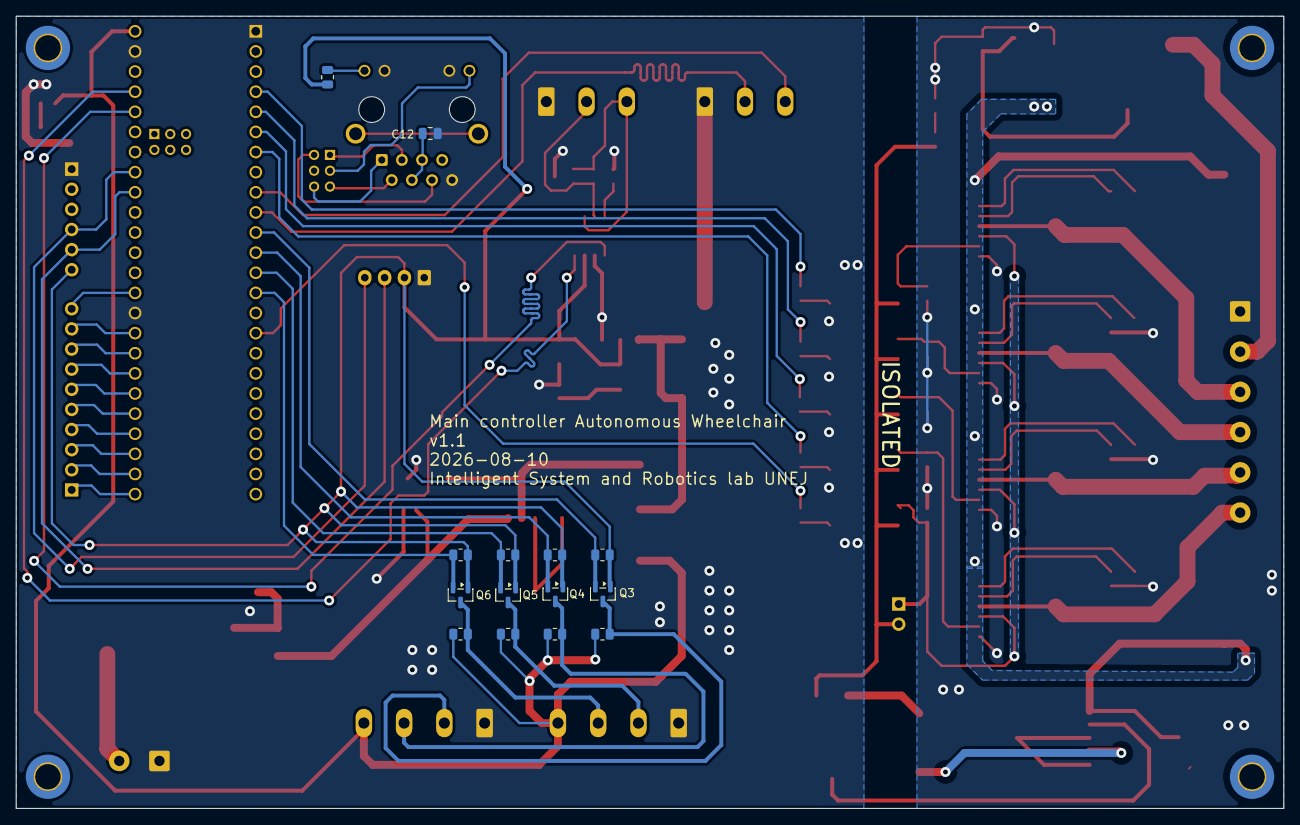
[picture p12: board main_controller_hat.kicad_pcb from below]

Board: 6 copper layers, 160.0 x 100.0 mm, 95 parts (14 on the bottom side), 78 nets.

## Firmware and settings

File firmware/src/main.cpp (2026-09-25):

// ===========================================================================
// src/main.cpp
//
// Minimal ROS Serial Template for Teensy 4.1
// ===========================================================================

#include <Arduino.h>
#include <ros.h>
#include <geometry_msgs/Twist.h>
#include <wheelchair_msgs/EncoderHeading.h>

// ---------------------------------------------------------------------------
// ROS Node Handle, Messages, Publishers, and Subscribers
// ---------------------------------------------------------------------------
ros::NodeHandle nh;

// Message instance to publish
wheelchair_msgs::EncoderHeading encoderMsg;
ros::Publisher encoderPub("encoder_heading", &encoderMsg);

// Callback function for /cmd_vel subscriber
void cmdVelCallback(const geometry_msgs::Twist &msg) {
    // TODO: Process incoming Twist commands (msg.linear.x, msg.angular.z)
}

ros::Subscriber<geometry_msgs::Twist> cmdVelSub("cmd_vel", &cmdVelCallback);

void setup() {
    // Initialize ROS node handle and register pub/sub
    nh.initNode();
    nh.subscribe(cmdVelSub);
    nh.advertise(encoderPub);
}

void loop() {
    // TODO: Populate encoderMsg fields before publishing
    // encoderMsg.left_ticks = ...;
    // encoderMsg.right_ticks = ...;
    // encoderMsg.heading = ...;
    // encoderMsg.stamp = nh.now();

    encoderPub.publish(&encoderMsg);

    // Handle incoming communication and maintenance
    nh.spinOnce();
    delay(10); // Adjust loop frequency/rate as needed
}

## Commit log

2026-08-11 chore: initial commit of wheelchair monorepo
2026-08-11 fix: convert main_controller_hat from submodule to regular directory
    [Block Diagram.kicad_sch, Power - Generation.kicad_sch, Power - Sequencing.kicad_sch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]
2026-08-13 main controller final design
    [KDT_Hierarchical_KiBot-bom-k8.csv, Project Architecture.kicad_sch, Section A - Title A.kicad_sch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]
2026-08-13 fix documentation: adding readme file
    [Bill of Material Autonomous Wheelchair Main Controller .xlsx]
2026-09-12 revise main controller with pc817
    [Project Architecture.kicad_sch, Section A - Title A.kicad_sch, Section B - TItle B.kicad_sch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]
2026-09-25 remove fuzzy PID lib
